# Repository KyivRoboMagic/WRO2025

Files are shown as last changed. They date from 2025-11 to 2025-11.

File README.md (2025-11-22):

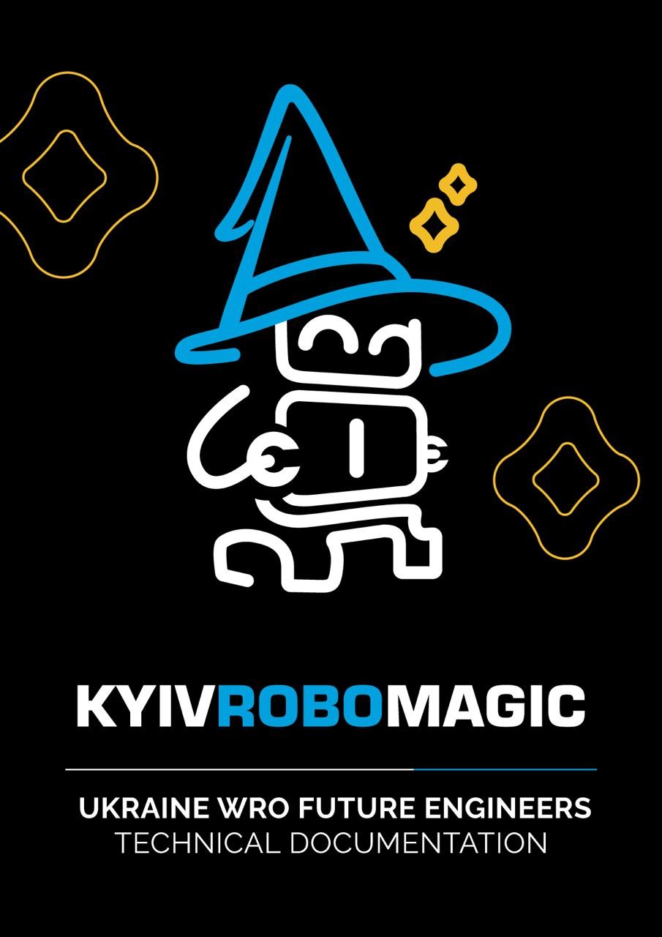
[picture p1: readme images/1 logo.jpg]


## Object Challenge: https://youtu.be/LZ57Y01bQvU

## Open Challenge: https://youtu.be/bDnhjbADkbo

# TABLE OF CONTENTS

INTRODUCTION — THE CAR THAT THINKS IN ANGLES (page 4)

## PART 1 — TEAM INTRO (page 6-9)
- 1.1. Who We Are
- 1.2. Our Ideology
- 1.3. Team Members
- 1.4. Preparation to WRO 2025
- 1.5. Calendar

## PART 2 — ENGINEERING SOLUTION (page 10-15)
- 2.1. General Ideology – The Car That Thinks in Angles
- 2.2. Robot Photo and General Dimensions
- 2.3. System Integration Specification
  - 2.3.1. System Architecture Overview
  - 2.3.2. Integration Logic
  - 2.3.3. Mechanical Subsystem
  - 2.3.4. Electrical Subsystem
  - 2.3.5. Control Software
- 2.4. Innovative Abilities

## PART 3 — ROBOT CONSTRUCTION (page 18-53)
- 3.1. Building Robot — Necessary Materials and Instruments
- 3.2. Electrical Components — Core Power and Control Elements
- 3.3. Mechanical Elements
- 3.4. Core Structure Elements
  - 3.4.0. Introduction
  - 3.4.1. Frame System — Base and Structural Parts
  - 3.4.2. Axle and Bearing Assembly
  - 3.4.3. Differential Mechanism
  - 3.4.4. Steering and Hinge System
  - 3.4.5. Turn and Steering Transmission
  - 3.4.6. Wheel and Tire Assembly
  - 3.4.7. Auxiliary and Module Elements

## PART 4 — PERFORMANCE (page 53)
- 4.1. Open Challenge Round
  - 4.1.1. Program Logic Overview
  - 4.1.2. Program Flow Summary
  - 4.1.3. Software Module Reference Table
  - 4.1.4. Detailed Program Functions’ Description
- 4.1.5. Open Challenge Strategy and Tactics
  - 4.1.5.1. System Strategy — Autonomous Field Navigation
  - 4.1.5.2. Tactical Implementation — Coordinated Sensor Logic
- 4.2. Obstacle Challenge Round
  - 4.2.1. Strategy
  - 4.2.2. Program Flow Summary
  - 4.2.3. Software Module Reference Table
  - 4.2.4. Detailed Program Functions’ Description

## PART 5 — RESOURCES LIBRARY

# INTRODUCTION — THE CAR THAT THINKS IN ANGLES

This document presents the engineering concept and integration framework of the WRO Future Engineers 2025 project — **“The Car That Thinks in Angles.”**

Created by **Kyivrobomagic**, it reflects our practical engineering culture:  
precise where it must be, experimental where it can be.

The idea was simple — to design a robot that doesn’t just move,  
but **understands its movement**.

Each subsystem — from the semi-spherical drivetrain to the sensor fusion core —  
was built to *think in geometry*, not in lines.

Mechanical, electrical, and software layers are integrated into a single responsive platform,  
capable of autonomous navigation and spatial reasoning.

---

## **Key Design Priorities**

- **Adaptive geometry:** torque transfer through a semi-spherical gear system allowing full-angle articulation.  
- **Sensor fusion:** LiDAR, IMU, and camera coordination for stable perception under any conditions.  
- **Power efficiency:** UPS-based 18650 system with DC-DC boost for 12 V drive and 5 V control logic.  
- **Real-time control:** multi-threaded C++ architecture ensuring predictive, low-latency motion.  

---

Every Kyivrobomagic robot carries a small dose of what we call **“engineering magic”** —  
not mystery, but **elegant simplicity** that makes a complex system work naturally.

This year, that magic is **geometry itself**.

# PART 1: TEAM INTRO

## **Who We Are**

We are **Kyivrobomagic** — a robotics team born in **2018 in Kyiv, Ukraine**.

Our team has changed over time, but the heart of it has always been the same:  
**Petro Moroz** and **Mark Biryukov**.

Together, we’ve grown into one of the **most awarded robotics teams from Ukraine**.

<p align="center">
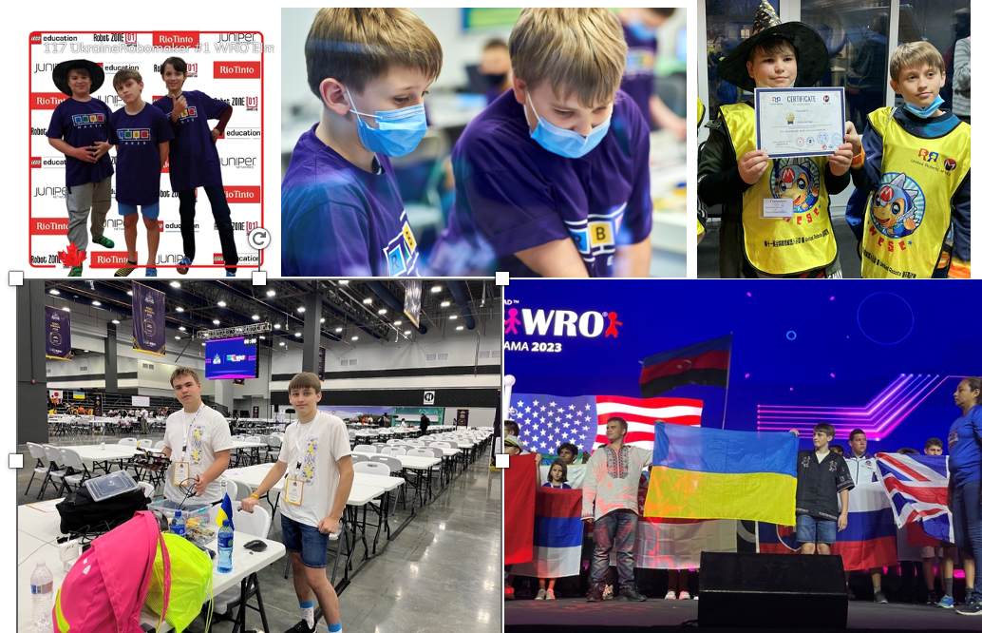
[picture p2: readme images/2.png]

</p>

## **Our Journey**

Our journey has been incredible.  
In **2020**, we earned **1st place** at **WRO Elementary**,  
in **2021** we took **silver**,  
then added another **silver at WRO Junior in Panama (2023)**,  
and reached the **Top 10 in Turkey (2024)** in the **Future Engineers** category.

But our story isn’t only about WRO.  
Each contest has taught us something new and made us stronger as a team.  
They brought fresh ideas, pushed us to think like real engineers, and inspired us to go further.

With every challenge, we learned not just how to build better robots,  
but also how to work together, solve problems creatively, and never give up.

For us, robotics is more than medals —  
it’s about **curiosity, friendship, and proving that Ukrainian kids can compete and win** on the world stage.

---

## **Our Ideology**

From the very beginning, our team has always appeared at competitions **dressed as wizards**.  
We are inspired by the famous quote:

> *“Any sufficiently advanced technology is indistinguishable from magic.”*

For us, it’s far more than words.  
At every competition, in every solution, we strive to create something so refined and well‑crafted  
that it amazes everyone and truly **feels like magic**.

We spend long hours working on programming and engineering,  
pouring not only knowledge but also imagination and creativity into our projects.

This is our philosophy:  
to transform complex technologies into something that inspires, fascinates, and opens new possibilities.  
**Technology as magic — and it is this magic that drives us forward.**

---

## **Team Members**

### **Petro Moroz — Engineering & Software**

In the team, Petro is responsible for engineering solutions, their implementation, and programming.  
For him, a robot is like a best friend, and every competition is a personal challenge.

He always strives to come up with something new —  
yet as simple and elegant as possible — to solve the tasks in the most efficient way.

Petro is also a talented coder — he likes to joke that he knows more programming languages than human ones.  
He proved his skills by taking **2nd place in Ukraine in programming among 9th graders**.

<p align="center">
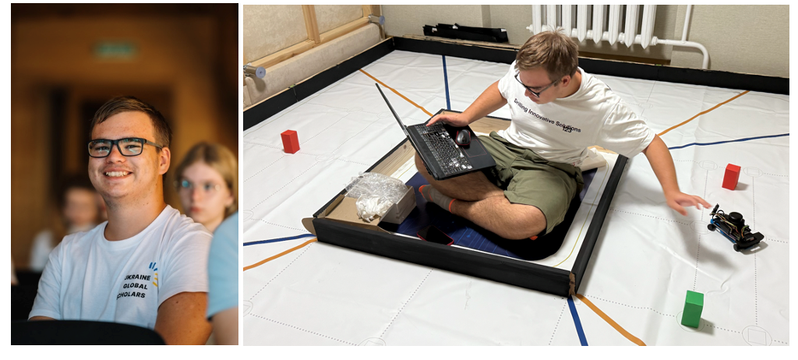
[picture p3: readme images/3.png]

</p>

## **Mark Biryukov — Software & Team Coordination**

Mark is responsible for software development and team coordination.  
He can find common ground with anyone and is a talented **mathematician and programmer**,  
a multiple prizewinner of math and programming Olympiads.

His greatest skill is his **incredible speed in finding solutions**.  
Mark quickly tests and implements ideas, helping the team move forward fast.

Thanks to his speed, energy, and openness, the team easily builds connections,  
communicates with ease, and always keeps a fun and positive spirit.

He is the team’s **“social glue.”**

<p align="center">
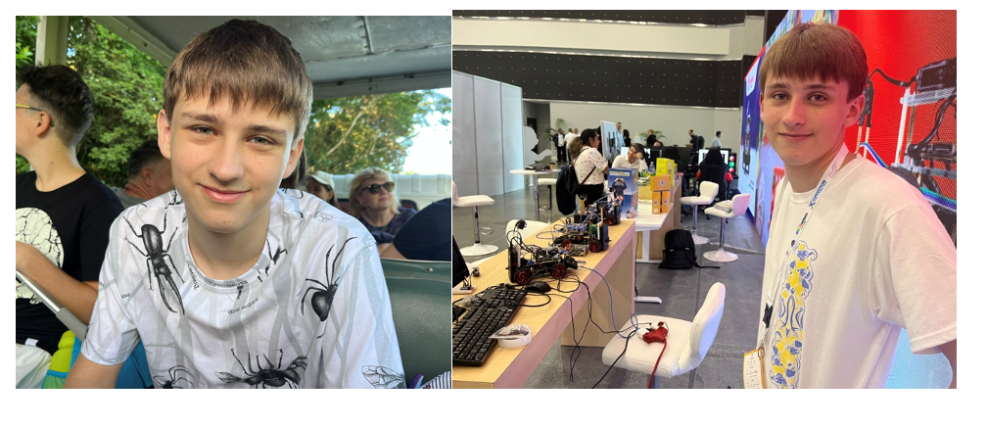
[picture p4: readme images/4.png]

</p>

## **Kyrylo Moroz — Design & Identity**

Our story wouldn’t be complete without mentioning our biggest fan and friend —  
**Petro’s younger brother, Kyrylo Moroz**.

He is only **12 years old**, but he is the one responsible for our **logo**,  
team **identity**, and making sure that everything about our team  
looks **stylish**, **consistent**, and **creative**.

Thanks to Kyrylo, our work is not only about engineering and programming,  
but also about **design, presentation, and imagination**.

<p align="center">
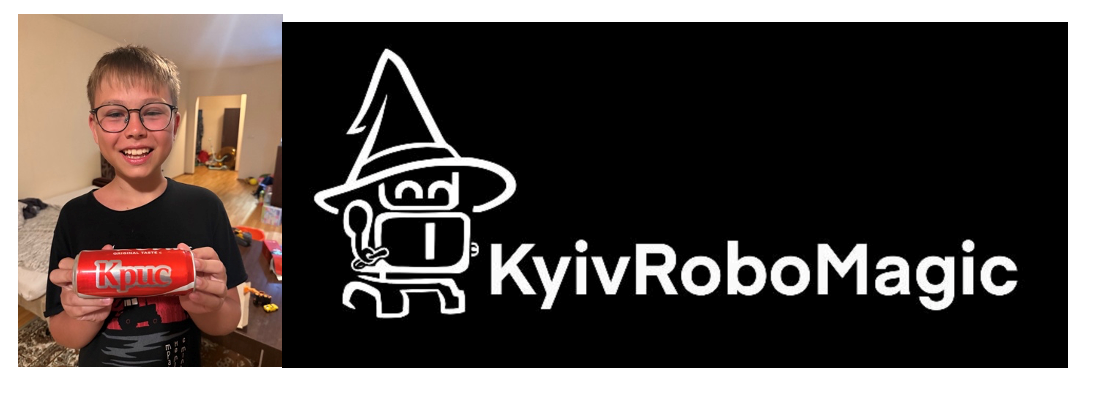
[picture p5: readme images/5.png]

</p>

## **Preparation to WRO 2025**

### **Logistic challenge as the main issue**

Because of the war in Ukraine, we had to move our work fully online.  
**Mark is in Kyiv**, while **Petro is in Cherkasy**, where his grandparents live.

Another important point is that we work **without a coach**,  
since in Ukraine there are no trainers in this category.  
This makes our journey not only about robotics, but also about  
**self-education, self-organization, and discipline** —  
without which none of this would be possible.

The preparation itself is also a challenge because of logistics.  
We break it into stages:

---

## **1. Research & Information Gathering**

We already had experience in the **Future Engineers** category last year,  
which gave us a strong foundation.

Still, we spent a lot of time studying the latest solutions for autonomous systems.  
For example, our chassis design is based on a **patented engineering idea**  
that had never been manufactured before.

Turning it from an abstract idea into a working prototype  
made us the first to implement it — and that’s where the **“magic”** begins.

---

## **2. Invention & Prototyping**

Most of the robot development takes place in Petro’s **“home lab” in Cherkasy** —  
actually, his and his brother’s bedroom 🙂 — equipped with a **3D printer**  
and access to parts.

We are always connected online, exchanging ideas  
and guiding the next steps of technical development.

---

## **3. Programming & Testing**

At this stage, we begin traveling to meet each other on weekends.  
This means spending **about three hours on the road** back and forth  
just to work together in person, test programs, and fine‑tune the design.

---

## **4. Finalization (Mini‑Camp)**

We plan the final stage as a **one‑week mini‑camp**  
during the autumn school break in October.

This is when we meet, live, and work together,  
finalizing the solutions we’ve been building for months.

---

# **Calendar**

Structurally, our preparation calendar looked like this.  
Since we are now in our final school years,  
it was especially important to stay on schedule  
and avoid major overlaps with exams and studies — and we managed to do so successfully.

We divided our work into clear stages, planned around school and competitions,  
which allowed us to maintain discipline, balance learning and robotics,  
and stay fully prepared for every challenge.

<p align="center">
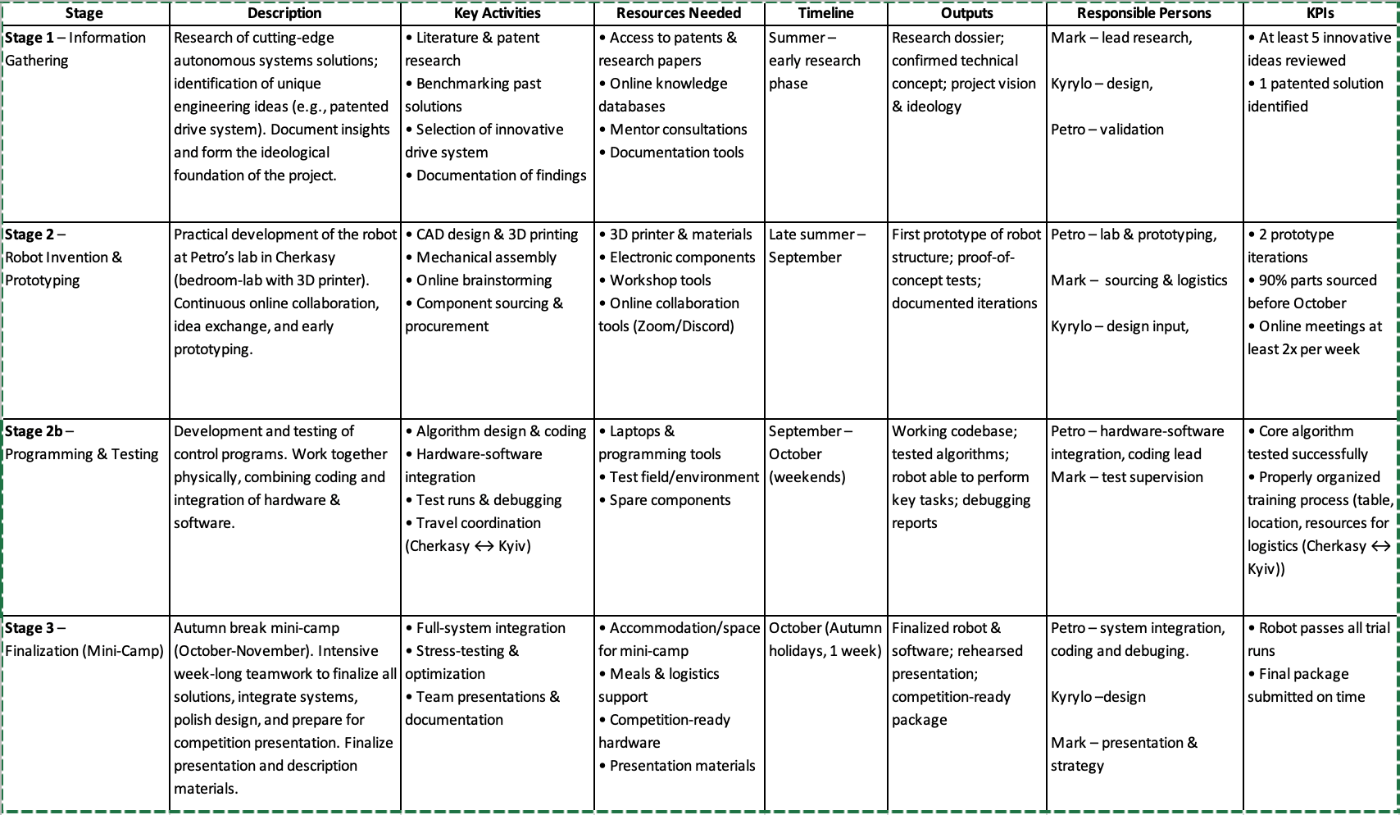
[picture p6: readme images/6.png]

</p>

# PART 2: ENGINEERING SOLUTION

## **General Ideology – The Car That Thinks in Angles**

### **1. From the Problem of Corners to the Geometry of Control**

Traditional vehicles are built for one-dimensional motion —  
they move forward and backward efficiently but lose precision when direction changes.

Most drivetrains are optimized for straight-line torque transfer,  
where every degree of deviation adds mechanical loss or instability.

This project started from a simple question:  
**can geometry itself improve control?**

Instead of treating steering angles as an obstacle,  
the robot uses them as part of its design logic.

The structure was built around the idea that **stability and control are not opposites** —  
they can be optimized together through geometry.

By rethinking how torque and direction interact,  
the robot achieves **smoother steering** and **higher mechanical accuracy**  
within a compact frame.

---

### **2. The Idea – The Car That Thinks in Angles**

The robot uses **one drive motor** and **one servo** to control all four wheels.  
Each wheel can rotate **up to 180°**, allowing:

- tight turning,  
- stable high-speed movement,  
- and minimal components without sacrificing precision.

The system relies on **mechanical synchronization**, not sensors on each wheel.  
The servo defines steering geometry,  
and the DC motor delivers torque.

Because all wheels are mechanically linked,  
motion remains consistent even at high rotation angles.

This design embodies **simplicity + reliability**:

- fewer moving parts,  
- fewer points of failure,  
- faster assembly,  
- easier debugging during competitions.

---

### **3. From Dimensions to Solutions**

Conventional robots operate in **two dimensions**: forward/backward and left/right.  
This system introduces a **third dimension — adaptive geometry**.

The robot dynamically adjusts orientation and turning angle  
based on real-time motion across the field.

To achieve this, it uses **three complementary sensors**:

- **LiDAR** — distance mapping + obstacle detection  
- **IMU** — stabilizes orientation between LiDAR updates  
- **Camera** — color, boundary, and line recognition  

Each sensor covers the weaknesses of the others.  
Together, they form a **robust and reliable perception system**  
even under variable lighting and surface conditions.

This setup is rare for WRO-level robots  
but proved **highly effective** in testing.

---

### **4. Key Technical Highlights**

#### **a) Unique Motion System**  
Each wheel rotates up to **180°**, yet the robot uses only **one motor + one servo**.  
This is extremely rare in competition robotics.

#### **b) Consistent Torque Delivery**  
The drivetrain maintains torque during steering through balanced geometry + load distribution.

#### **c) 3D-Printed Precision Components**  
Core parts — including advanced gear interfaces — were 3D-printed and tested.  
They demonstrate that **180° and even 360° torque transfer** is possible at this scale.

#### **d) Triple-Sensor Fusion**  
LiDAR + IMU + Camera → combined for superior navigation and robustness.

#### **e) Mechanical Reliability and Future Use**  
All components were validated under real competition conditions.  
They now form a **mechanical base** for future robot designs.

---

### **5. Summary**

**“The Car That Thinks in Angles”** is a compact and efficient robotic system  
that uses minimal components to achieve full control of movement.

The result is a **stable**, **fast**, and **reliable** platform  
that pushes the limits of what a single-motor robotic vehicle can do.

Every subsystem — drive, steering, sensing, structural design —  
was shaped through testing and iteration.

Its architecture blends:

- mechanical precision  
- geometric efficiency  
- sensor integration  

into one practical and elegant engineering solution.

---

# **Robot Photo and General Dimensions**

<p align="center">
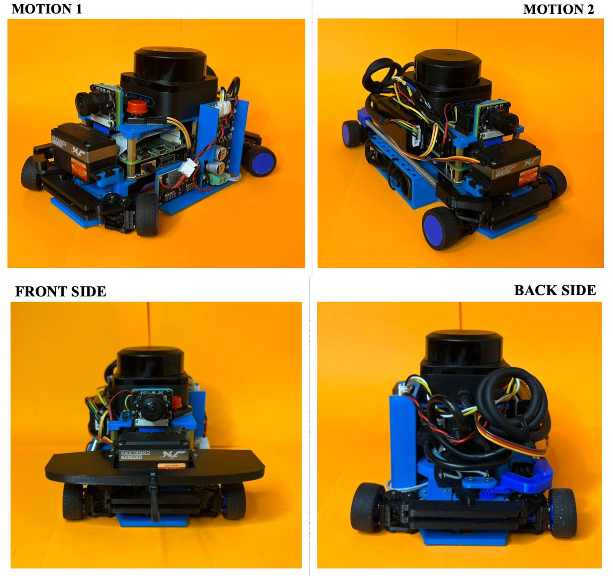
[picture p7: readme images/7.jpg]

</p>

<p align="center">
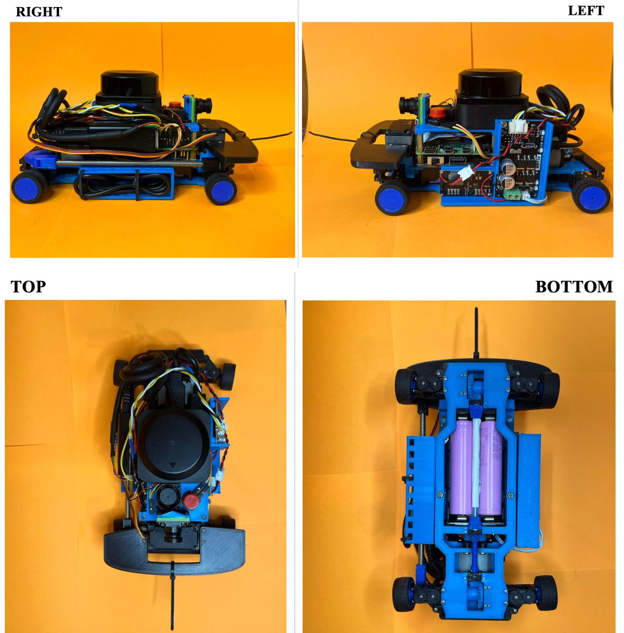
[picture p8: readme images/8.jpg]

</p>

## **Robot Dimensions**
- **Length:** 24 cm  
- **Width:** 12 cm  
- **Height:** 10 cm  

---

# **SYSTEM INTEGRATION SPECIFICATION**

## **1. System Architecture Overview**

The robot integrates four independent drive wheel modules, each connected through a **semi-spherical bevel gear system** inspired by patent **US5129275A**.

All four wheels are driven by a **single JGB37-520 12 V DC motor** through two differential units — one on each side — linked by the **main transmission shaft**.

Steering of all wheel modules is performed simultaneously by a **single global servo (JX PDI-4409MG)** providing up to **180° articulation** per wheel.

Each differential transfers torque to two wheel modules installed on custom 3D‑printed housings, enabling free rotation under multiple steering angles with balanced torque.

A **Raspberry Pi** coordinates all subsystems, processes sensor data, and controls motor + servo through PWM and digital channels.

### **Core components**
- **Motor:** JGB37-520 DC Motor (12 V)  
- **Motor Driver:** Cytron MD13S (PWM ≤ 20 kHz)  
- **Servo:** JX PDI-4409MG (180° steering)  
- **Main Controller:** Raspberry Pi 4 Model B (8 GB)  
- **Power Source:** UPS HAT with 2 × 18650 Li-ion (7.4 V nominal)  
- **Voltage Regulation:** TPS61088 (5V → 12V boost)  
- **Sensors:** RPLIDAR S3, BNO085 IMU, Waveshare OV5647 Camera  
- **Chassis:** Fully custom 3D‑printed modular frame  

---

## **2. Integration Logic**

The **Raspberry Pi 4B** generates PWM for the Cytron MD13S and the steering servo.  
The motor driver regulates torque and speed; the servo defines steering geometry.

### **Power Distribution**
- UPS HAT powers control electronics (**5 V / 3.3 V**)  
- TPS61088 boosts **5 V → 12 V** for the DC motor  
- 2S Li-ion battery pack is the unified input  

### **Sensor Interfaces**
- **LiDAR:** USB (mapping + obstacle detection)  
- **IMU (BNO085):** I²C (orientation, stabilization)  
- **Camera:** CSI ribbon cable (vision processing)  

The Pi fuses all sensor data, computes navigation in C++, and sends real‑time motion commands.

---

## **3. Mechanical Subsystem**

A fully custom 3D‑printed semi-spherical bevel gear system distributes torque from the motor into two side differentials.

Each differential powers two wheel modules via compact coupling shafts.

This structure:
- preserves wheel orientation at any steering angle  
- minimizes friction  
- simplifies replacement of subassemblies  
- maintains alignment across the chassis  

---

## **4. Electrical Subsystem**

| Component | Function | Specification |
|---|---|---|
| **Power Source** | Primary supply | 2 × 18650 Li-ion (7.4 V, 2S) |
| **Voltage Regulation** | Boost 5V → 12V | TPS61088, 30 W |
| **Power Distribution** | Logic rails | UPS HAT B |
| **Motor Driver** | Drive control | Cytron MD13S (13 A, 6–30 V) |
| **Motor** | Main torque | JGB37-520 DC Motor (12 V) |
| **Servo** | Steering | JX PDI-4409MG |
| **Sensors** | Perception | LiDAR S3, BNO085, OV5647 Camera |
| **Controller** | Navigation | Raspberry Pi 4B (8 GB) |

---

## **5. Control Software**

- **C++** → motor control, navigation logic  
- **Python** → IMU interface  
- **PWM** → drive + steering actuation  
- **Sensor fusion** → LiDAR + IMU + Camera  
- **Feedback loops** → heading + stability correction  

---

## **Summary**

The system integrates:
- single‑motor + global‑servo drivetrain  
- adaptive sensing  
- efficient power management  

Resulting in a compact, stable, full‑angle steering platform with reliable sensing and control.

---

## **Innovative Abilities**

| Ability | Description |
|---|---|
| **Full‑Torque Steering** | Maintains torque during 180° wheel rotation |
| **Adaptive Response** | LiDAR + IMU + Camera fusion for stable navigation |
| **Efficient Power Control** | UPS HAT + TPS61088 ensure stable motor + logic power |

# PART 3: ROBOT CONSTRUCTION

## **Building Robot – Necessary Materials and Instruments**

## **1. 3D Printer: Ender V3 — Detailed Usage & Specifications**

<p align="left">
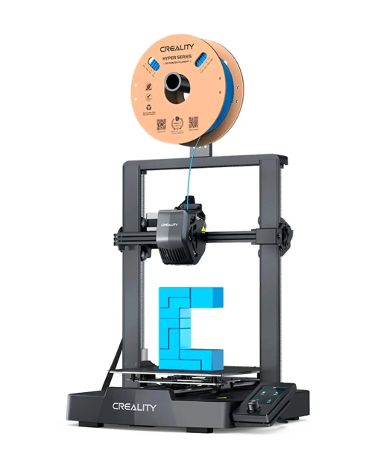
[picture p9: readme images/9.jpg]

</p>

This is the printer personally owned and used in my workshop for all prototype and final component manufacturing.  
It was used to fabricate the majority of the robot’s mechanical and structural parts.

Its **automatic bed leveling system** saves significant setup time —  
a major advantage, as manual leveling is often one of the most time‑consuming and error‑prone steps in 3D printing.

Using a **0.2 mm nozzle** enabled the production of small, detailed parts with:
- superior dimensional accuracy  
- smooth surface finish  
- tight bearing alignment  
- reliable tolerance for rotating assemblies  

These characteristics were crucial for the semi‑spherical gear interfaces, differential units, and steering components.

---

## **Ender V3 Technical Specifications**

| **Parameter** | **Specification** |
|---|---|
| **Type** | FDM (Fused Deposition Modeling) |
| **Build Volume** | 220 × 220 × 250 mm |
| **Recommended Filament Types** | PLA, PETG, TPU |
| **Filament Diameter** | 1.75 mm |
| **Nozzle Diameter** | 0.2 mm (standard, interchangeable) |
| **Nozzle Temperature Range** | up to 260 °C |
| **Bed Temperature Range** | up to 100 °C |
| **Layer Resolution** | 0.1 – 0.35 mm |
| **Print Speed** | up to 180 mm/s (recommended ≤ 120 mm/s for precision) |
| **Automatic Leveling** | CR Touch Sensor + strain gauge Z‑offset calibration |
| **Connectivity** | SD card, USB‑C |
| **Control Interface** | 4.3″ color display with Creality OS |
| **Frame** | All‑metal structure with dual Z‑axis & belt tensioners |
| **Supported File Formats** | STL, OBJ, AMF, G-code |
| **Slicing Software** | Creality Print, Cura, PrusaSlicer |
| **Power Supply** | 100–240 V AC (50/60 Hz) |
| **Noise Level** | < 45 dB (silent stepper drivers) |
| **Printer Dimensions** | 490 × 490 × 510 mm |
| **Weight** | ≈ 7.1 kg |

---

## **2. Printing Plastic**

<p align="center">
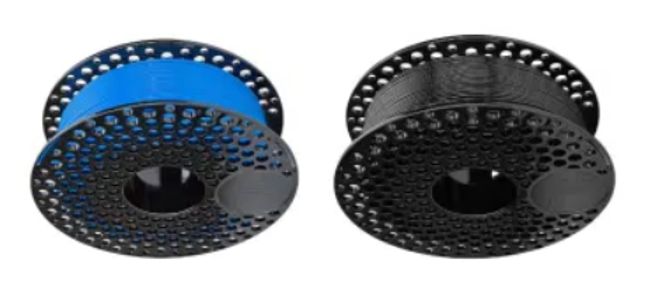
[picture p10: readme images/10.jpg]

</p>

The color itself is not critical, but it can slightly affect surface texture, print strength,  
and layer bonding. In my experience, **black PETG from CR** produced the most stable  
and consistent results on the Ender‑3 V3 printer.

The printer operates optimally at **230 °C nozzle temperature**,  
but users should run small calibration prints to tune performance  
for their specific filament brand and ambient environment.

Mechanical and aesthetic properties vary among manufacturers,  
so it's recommended to check **public filament tests** and **community benchmarks**  
before printing structural components such as gears, holders, and load‑bearing frames.

---

## **PETG Technical Specifications**

| **Parameter** | **Specification** |
|---|---|
| **Filament Type** | PETG (Polyethylene Terephthalate Glycol) |
| **Color** | Black / Blue |
| **Filament Diameter** | 1.75 mm |
| **Printing Temperature Range** | 230 – 250 °C |

---

# ELECTRICAL COMPONENTS — CORE POWER AND CONTROL ELEMENTS

## **1. Raspberry Pi 4 Model B – Central Control Unit**

<p align="left">
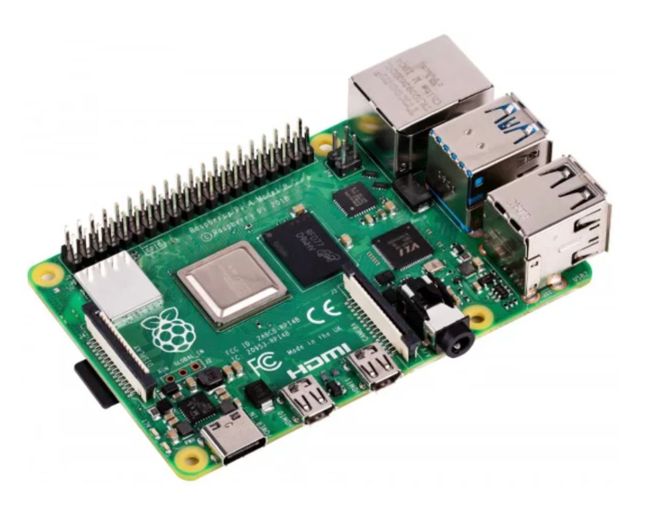
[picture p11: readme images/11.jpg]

</p>

This board serves as the **central control and coordination unit** of the robot.  
It manages all communication channels, motor coordination, and sensor data processing.

Thanks to its processing capacity, it can **simultaneously handle**:

- LiDAR data  
- IMU readings  
- Camera input  
- Motor control tasks  

The main navigation + control logic is written in **C++**, ensuring high-speed, low-latency execution.  
A lightweight **Python** script interfaces the **BNO085 IMU** library, simplifying data access and fusion.

An **UPS HAT (B)** module provides uninterrupted power, reducing development time, increasing reliability,  
and protecting the Raspberry Pi from power drops during motor load spikes.

The Raspberry Pi 4B was chosen for its:

- strong community support  
- abundant documentation  
- compatible peripherals  
- excellent performance for real-time robotics  

---

## **Raspberry Pi 4 Model B — Technical Specifications**

| **Parameter** | **Specification** |
|---|---|
| **Model** | Raspberry Pi 4 Model B |
| **RAM** | 8 GB LPDDR4 3200 |
| **Processor** | Broadcom BCM2711 — Quad-core Cortex A72 (ARM v8, 1.5 GHz) |
| **GPU** | VideoCore VI (OpenGL ES 3.x, Vulkan) |
| **Network / Connectivity** | Gigabit Ethernet, WiFi 2.4/5.0 GHz, Bluetooth 5.0, BLE |
| **USB Ports** | 2 × USB 3.0, 2 × USB 2.0 |
| **Display Outputs** | 2 × micro HDMI (dual displays up to 4K) |
| **Video / Audio** | H.265 4Kp60, H.264 1080p60, 4Kp30 encode/decode |
| **Storage Interface** | microSD slot |
| **Power Supply** | USB‑C 5.1 V / 3 A |
| **GPIO Header** | 40‑pin GPIO (Pi‑compatible) |
| **Dimensions** | 88 × 58 × 19.5 mm |
| **Operating Temperature** | 0°C to +50°C |
| **Operating System** | Raspberry Pi OS, Ubuntu, ARM Linux |
| **Typical Applications** | Robotics, IoT, education, desktop |
| **Manufacturer** | Raspberry Pi Ltd (UK) |
| **Official URL** | https://www.raspberrypi.com/products/raspberry-pi-4-model-b/ |

---

## **2. Sunon KD0501PFB3-8 Micro Fan – Essential Cooling Element**

Although small, this fan plays a **critical role in maintaining thermal stability** of the system.  
Without active cooling, the **Raspberry Pi 4 overheats within minutes**, reaching temperatures where the CPU throttles  
and can no longer operate reliably.

This miniature fan dramatically improves cooling performance — lowering the CPU temperature so the board stays:

- stable  
- responsive  
- touch-safe  
- fully operational under maximum load  

To reduce **noise and vibration**, a thin layer of **double‑sided adhesive tape** was placed between the fan and the 3D‑printed frame.  
This acts like soft **acoustic foam**, absorbing micro‑vibrations and preventing resonance with the chassis.

As a result, the fan becomes **almost silent** while maintaining full airflow efficiency.

---

## **Sunon KD0501PFB3-8 — Technical Specifications**

<p align="left">
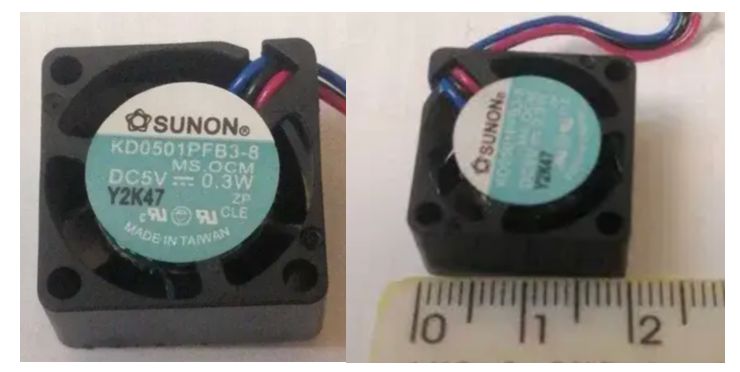
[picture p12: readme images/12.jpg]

</p>

| **Parameter** | **Specification** |
|---|---|
| **Type** | DC Brushless Cooling Fan |
| **Manufacturer** | Sunon |
| **Model** | KD0501PFB3-8 |
| **Dimensions** | 20 × 20 × 10 mm |
| **Rated Voltage** | 5 V DC |
| **Operating Voltage Range** | 3.5 – 5.5 V |
| **Rated Current** | 0.06 A |
| **Rated Power Consumption** | 0.3 W |
| **Rated Speed** | 10,000 ±15% RPM |
| **Air Flow** | 1.0 CFM |
| **Static Pressure** | 3.6 mm H₂O |
| **Noise Level** | 22 dBA |
| **Bearing Type** | Vapo Bearing (MagLev technology) |
| **Connector Type** | 2-wire (Red +, Black –) |
| **Frame Material** | Thermoplastic (UL 94V-0) |
| **Weight** | ~4 g |
| **Operating Temperature Range** | –10 °C to +70 °C |
| **Expected Life** | 50,000 hours @ 40 °C |

---

## **3. RPLIDAR S3 – High-Precision 2D LiDAR Scanner**

<p align="left">
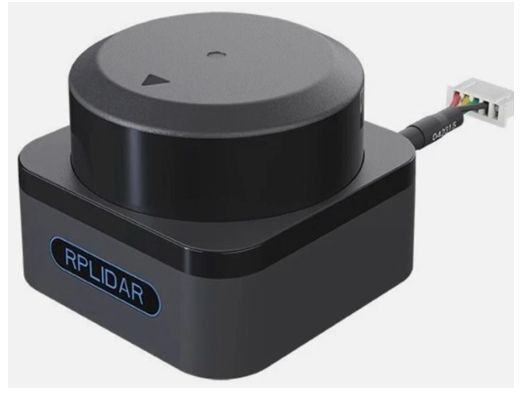
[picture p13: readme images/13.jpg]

</p>

This LiDAR sensor became a **turning point** in the robot’s spatial awareness system.

In the previous generation, the robot relied solely on the **camera for navigation**, meaning it had **no memory of its environment** — every run started “from zero.”  

With the introduction of the **RPLIDAR S3**, the robot can now:

- build a persistent **2D map** of its surroundings  
- perform **precise localization**  
- correct its path in real time  
- operate reliably regardless of lighting or color conditions  

Unlike the camera, the LiDAR is **immune to lighting changes**, shadows, reflections, and color inconsistencies.  
Earlier robots often confused:

- **red cubes** with **orange lines**,  
- **gray walls** with the **floor**,  
- or misread the field under shifting lighting conditions.

The RPLIDAR S3 eliminates these problems completely.

By combining **LiDAR mapping** with **IMU-based orientation correction**, the robot achieves:

- unprecedented stability  
- high navigation accuracy  
- reliable field awareness  

allowing the camera to focus **only on object detection**, not full scene interpretation.

---

## **RPLIDAR S3 — Technical Specifications**

| **Parameter** | **Specification** |
|---|---|
| **Model** | RPLIDAR S3 |
| **Type** | 2D 360° laser scanner (DTOF / SL TOF) |
| **Distance Range (70% refl.)** | 0.05–40 m |
| **Distance Range (10% refl.)** | 0.05–15 m |
| **Distance Range (2% refl.)** | 0.05–5 m |
| **Blind Range** | 0.05 m |
| **Sampling Rate** | Up to 32 kHz |
| **Scan Frequency** | 10–20 Hz |
| **Angular Resolution** | 0.1125°–0.225° |
| **Ranging Resolution** | 10 mm |
| **Range Accuracy** | ±30 mm |
| **Ambient Light Immunity** | ≥80,000 Lux (sunlight resistant) |
| **Communication Interface** | TTL UART (1 Mbit/s) |
| **Laser Safety** | Class 1 (eye safe) |
| **Power Supply** | 5 V DC, ~500 mA |
| **Dimensions** | 59.8 × 55.6 × 41.3 mm |
| **Weight** | ~115 g |
| **Operating Temperature** | –10 °C to +60 °C |
| **Applications** | Robotics, AGV/AMR, SLAM, UAV avoidance |
| **Manufacturer** | SLAMTEC (China) |
| **Official URL** | https://www.slamtec.com/en/S3 |

---

## **4. Waveshare OV5647 5 MP Wide-Angle Camera Module — Technical Description**

<p align="left">
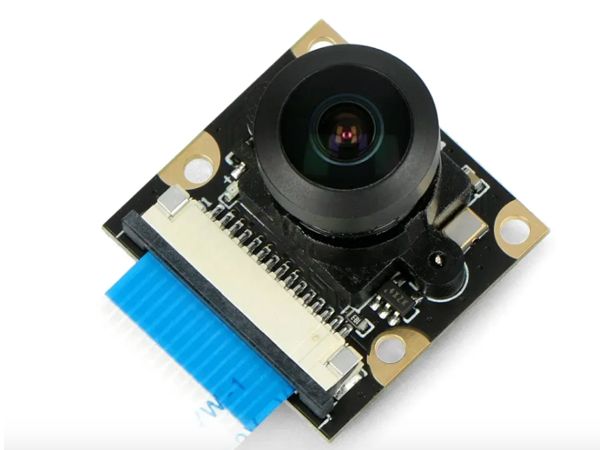
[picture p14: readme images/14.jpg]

</p>

This camera module is the same model used in last year’s robot design.  
It is built on the **OV5647 5‑megapixel sensor** and operates natively with all **Raspberry Pi boards** via the CSI interface.

Despite being lightweight and simple, it is **highly optimized for Raspberry Pi**, providing stable and predictable behavior in robotics applications.

The camera captures **RGB images at up to 30 FPS (640×480)**.  
Although modest compared to modern high‑speed camera systems, this performance is **fully sufficient for fast robot movement** when paired with efficient image-processing algorithms.

### **Wide-Angle Advantage (160° FoV)**

A major benefit of this module is its **160‑degree wide-angle lens**, dramatically expanding the field of view.  
This allows the robot to:

- detect walls more reliably  
- track boundaries continuously  
- reduce blind spots  
- maintain stable navigation even in narrow or irregular field layouts  

### **Role in the New Architecture**

Unlike last year’s robot, **the camera no longer determines field position**.  
Localization is now handled entirely by the **LiDAR + IMU system**, resulting in:

- far higher positional stability  
- no more double-scanning of lines  
- reduced navigation errors  
- cleaner division of sensing roles  

The camera now focuses solely on:

- wall detection  
- color marker identification  
- boundary tracking  
- visual assistance in obstacle detection  

This separation significantly improves system accuracy and reduces computational load.

---

## **Waveshare OV5647 — Technical Specifications**

| **Parameter** | **Description / Value** |
|---|---|
| **Sensor Model** | OV5647 |
| **Image Sensor Type** | CCD, 1/4" |
| **Resolution** | 5 MP (2592×1944) |
| **Image Format** | RGB |
| **Supported Video Resolution** | Up to 1080p |
| **Max Frame Rate** | 30 FPS |
| **Recommended Mode** | 640×480 @ 30 FPS |
| **Field of View** | 160° wide-angle lens |
| **Standard FoV (base module)** | ~73° |
| **Connection Interface** | CSI |
| **Raspberry Pi Compatibility** | Pi 4B, 3B+, 3B, 2B, 1B, Zero series |
| **Zero Adapter Options** | 150 mm / 300 mm adapters |
| **Lens Characteristics** | Factory-mounted, Pi‑tuned optics |
| **CPU Load** | Minimal (hardware-accelerated pipeline) |
| **Primary Purpose** | Wide-angle real-time vision |
| **Form Factor** | Direct CSI‑port camera module |

---

## **5. BNO085 9‑DOF IMU Fusion Breakout (Adafruit 4754) – Inertial Compensation System**

<p align="left">
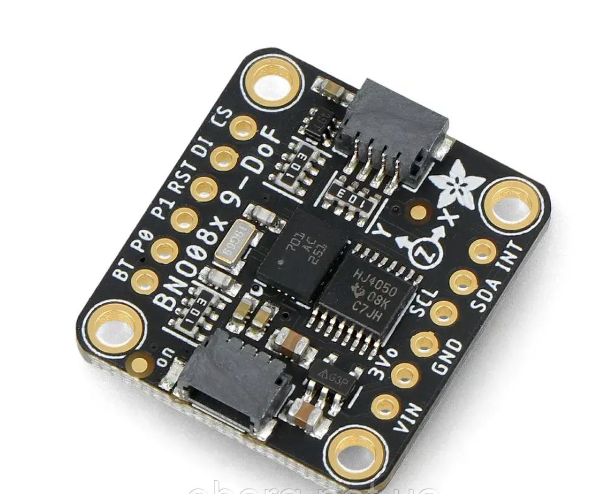
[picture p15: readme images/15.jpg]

</p>

While the RPLIDAR S3 provides spatial mapping, it operates at roughly **one measurement every 100 ms**—an eternity in control‑loop terms (about one data point per ~10 cm of travel).  

The **BNO085 IMU** fills this temporal gap by delivering **continuous inertial data**, maintaining motion awareness between LiDAR samples.

Although IMUs experience long‑term drift, their **short‑term accuracy** makes them ideal for interpolating robot motion between LiDAR frames, ensuring:

- smooth trajectory estimation  
- stable orientation  
- consistent turning logic  

### **Integration Challenge**

Integrating this IMU was one of the most challenging stages of the build:

- **SPI communication failed** due to unstable responses and noise.  
- Consultation with **Bryan Siepert** (BNO085 library author) confirmed SPI is unreliable in this configuration.  
- **I²C also failed initially**, not initializing consistently.  

The breakthrough came from using the **official Python driver**, which proved fully stable.  
A small Python service now runs in parallel with the C++ navigation engine:

- Python module → handles IMU fusion & quaternions  
- C++ program → receives results via internal data pipe  

This hybrid architecture merges the **reliability of Python** with the **performance of C++**.

---

## **BNO085 — Technical Specifications**

| **Parameter** | **Specification** |
|---|---|
| **Model** | BNO085 9-DOF IMU Fusion Breakout (Adafruit 4754) |
| **Function** | 3-axis accelerometer + 3-axis gyroscope + 3-axis magnetometer with fusion |
| **Processor** | ARM Cortex M0 running CEVA SH-2 firmware |
| **Sample Rate** | Up to 1 kHz |
| **Report Types** | Orientation, quaternion, lin. acceleration, gravity, raw/calibrated data, motion detection |
| **Interface** | I²C (default), optional UART/PSI |
| **Logic Voltage** | 3.3 V (5 V tolerant) |
| **Power Supply** | 3.3–5 V |
| **Dimensions** | 25.6 × 22.7 × 4.6 mm |
| **Weight** | ~2.5 g |
| **Mounting** | Breakout board + STEMMA QT/Qwiic |
| **Operating Temperature** | –40 °C to +85 °C |
| **Communication Speed** | I²C up to 400 kHz / UART 115,200 bps |
| **Applications** | Robotics, AR/VR, tracking, IMU fusion |
| **Manufacturer** | Adafruit / Hillcrest Labs |
| **Official URL** | https://www.adafruit.com/product/4754 |

---

## **6. Waveshare UPS HAT (B) – Uninterruptible Power Supply Module for Raspberry Pi**

<p align="left">
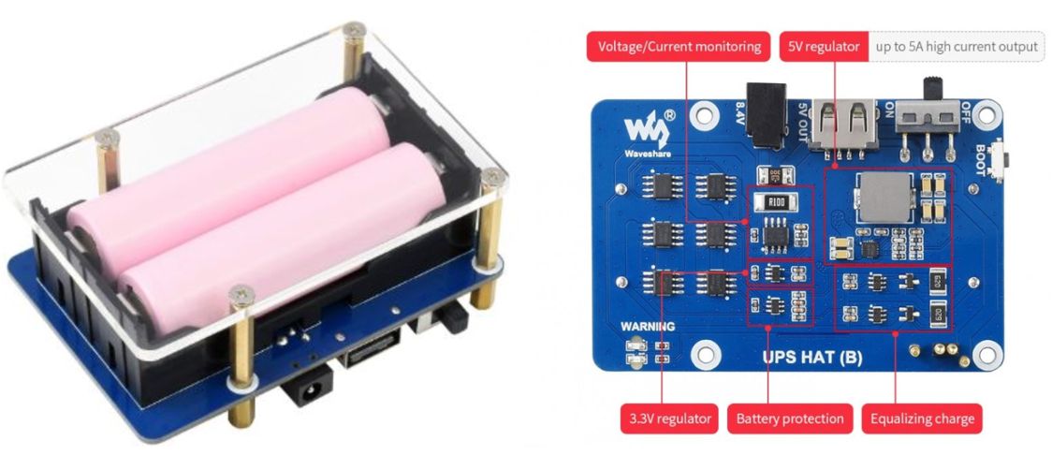
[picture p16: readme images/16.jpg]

</p>

The **Waveshare UPS HAT (B)** serves as the **primary power-stabilization unit** for the robot’s control system, ensuring continuous and stable operation of the Raspberry Pi 4 and all electronics even under dynamic motor loads.

In the previous year’s design, frequent **brown-out events** occurred — moments when sudden current spikes from motors or servos caused the Raspberry Pi to reboot.  
This UPS module **eliminates that problem entirely**:

- delivers **up to 5 A** continuous current  
- provides **stable 5 V and 3.3 V rails**  
- includes **real‑time battery monitoring** through I²C  
- **continues powering the Pi even while charging**  
- routes all power **through the UPS**, preventing undervoltage drops  

Although physically large and challenging to integrate mechanically, the reliability improvement is dramatic and essential for uninterrupted LiDAR, IMU, and camera processing.

---

## **Waveshare UPS HAT (B) — Technical Specifications**

| **Parameter** | **Specification** |
|---|---|
| **Model** | Waveshare UPS HAT (B) |
| **Output Voltage** | 5 V DC regulated |
| **Max Output Current** | Up to 5 A continuous |
| **Charger Input** | 8.4 V / 2 A |
| **Control Bus** | I²C — live monitoring (voltage, current, power, remaining capacity) |
| **Battery Support** | 2 × 18650 Li-ion cells |
| **Battery Protection** | Overcharge, overdischarge, overcurrent, short circuit, reverse polarity, balancing charge |
| **Automatic Switchover** | Yes — seamless transition to battery when power fails |
| **GPIO / Connector** | Pogo-pin connector (minimal GPIO usage) |
| **Compatibility** | Raspberry Pi 3 / 3B+ / 4B (+ likely Pi 5) |
| **Communication Interface** | I²C @ address 0x36 (BQ27441 or equivalent) |
| **Dimensions** | 56 × 85 mm |
| **Mounting Hole Size** | 3.0 mm |
| **Operating Temperature** | 0 °C – 50 °C |
| **Manufacturer** | Waveshare International |
| **Applications** | Robotics, Raspberry Pi UPS, industrial IoT |
| **Official URL** | https://www.waveshare.com/wiki/UPS_HAT_(B) |

---

## **7. DC‑DC Step‑Up (Boost) Module – TI TPS61088**

<p align="left">
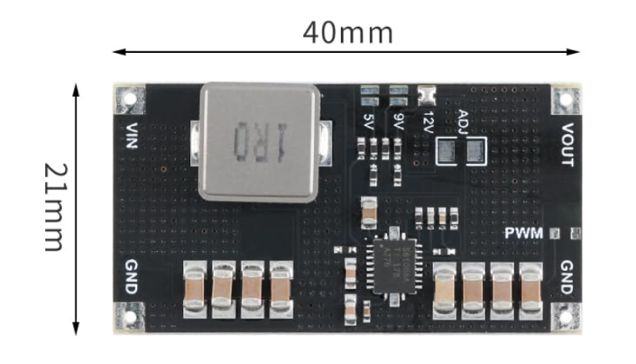
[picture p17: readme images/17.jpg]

</p>

This module plays a **critical role in power conversion**, boosting the 5 V rail from the UPS HAT (B) to the **12 V required** by the Cytron MD13S motor driver and the robot’s DC gear motors.

The **TPS61088** chip is well known for its **exceptional current capability** — up to **10 A peak**, far exceeding typical hobby-grade converters (2.5–5 A).  
This higher margin ensures:

- stable motor torque  
- no voltage sag during acceleration or turning  
- clean, synchronized drivetrain behavior  

Despite its compact size, the module offers:

- precise output tuning via onboard potentiometer  
- optional configuration headers  
- high efficiency and robust protection  

In this robot, the converter forms the **power bridge** between:

- **5 V logic system** (UPS HAT output)  
- **12 V actuator rail** (motor + driver supply)

It was carefully calibrated for **stable 12 V** operation even under rapid motor load variations.

---

## **TI TPS61088 Boost Converter — Technical Specifications**

| **Parameter** | **Specification** |
|---|---|
| **Module / IC** | DC-DC Step-Up (Boost) – TI TPS61088 |
| **Input Voltage** | 2.7–10 V DC |
| **Output Voltages** | 5 V / 9 V / 12 V selectable |
| **Max Output Power** | Up to 30 W |
| **Typical Output Capability** | 5 V → 5–6 A, 9 V → 3.3 A, 12 V → 2.5 A |
| **Efficiency** | Peak > 95% |
| **Switching Frequency** | ~200 kHz–2.2 MHz (typically ~1 MHz) |
| **Control Modes** | PFM/PWM auto or selectable |
| **Protection** | Overcurrent, cycle-by-cycle limiting, thermal shutdown |
| **Ripple / Noise** | Low with appropriate capacitors |
| **Inductor** | High‑current shielded (onboard) |
| **Operating Temperature** | –40 °C to +85 °C |
| **Dimensions** | Compact PCB module (varies by vendor) |
| **Reference Datasheet** | https://www.ti.com/lit/gpn/TPS61088 |

---

## **8. Cytron MD13S – 13A 6–30V DC Motor Driver**

<p align="left">
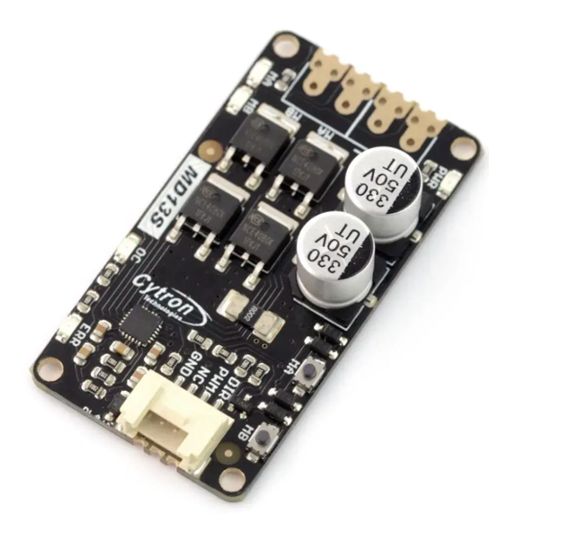
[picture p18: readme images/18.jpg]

</p>

The **Cytron MD13S** serves as the **main motor control unit** for each DC drive motor.  
It is a robust, competition‑grade driver designed for **high‑current, high‑stress** robotics applications.

Earlier prototypes used an L293D‑based driver, which failed during stress testing — specifically burning out during a collision when the motor produced a sudden reverse surge.  
The **MD13S handled the same tests without any damage**, thanks to:

- strong overcurrent protection  
- solid‑state H‑bridge design  
- high efficiency  
- 13 A continuous current capability  

Although physically larger than lighter alternatives, its **thermal stability**, **current margin**, and **plug‑and‑play simplicity** make it the ideal choice for the drivetrain.

Once installed, it requires almost no maintenance and performs flawlessly under continuous operation.

---

## **Cytron MD13S — Technical Specifications**

| **Parameter** | **Specification** |
|---|---|
| **Model** | Cytron MD13S 13A 6–30V DC Motor Driver |
| **Motor Channel** | 1 (Single brushed DC motor) |
| **Operating Voltage** | 6–30 V DC |
| **Continuous Current** | 13 A |
| **Peak Current** | 30 A (≤10 s) |
| **Logic Voltage** | 3.3 V / 5 V compatible |
| **PWM Frequency** | Up to 20 kHz |
| **Control Modes** | Sign‑Magnitude PWM / Locked‑Antiphase |
| **Direction Control** | DIR pin |
| **Connectors** | Terminal blocks (power & motor), GROVE logic connector |
| **Protection** | Over‑current limit, solid‑state H‑bridge, NMOS |
| **Efficiency** | ~95% |
| **Dimensions** | 61 × 33 mm |
| **Mounting Holes** | 4 × 3.2 mm |
| **Operating Temperature** | –10 °C to +60 °C |
| **Applications** | Robotics, automation, Arduino/RPi motor control |
| **Manufacturer** | Cytron Technologies |
| **Official URL** | https://www.cytron.io/p-13amp-6v-30v-dc-motor-driver |

---

## **9. JGB37-520 DC Gear Motor (12 V) – High-Power Drive Unit**

<p align="left">
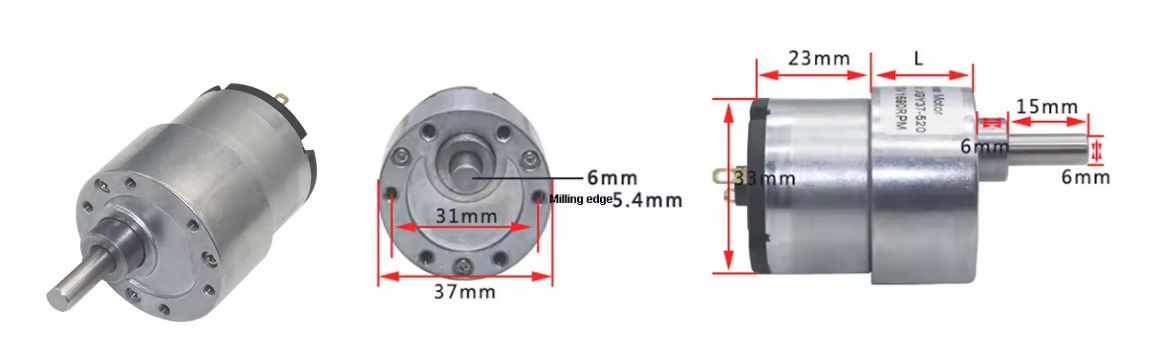
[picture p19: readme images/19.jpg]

</p>

This motor serves as the **main propulsion unit** for the robot’s four-wheel drive system, providing both forward and reverse motion.

Compared to last year’s robot, the current platform is **larger, heavier, and significantly more power-demanding**.  
Extensive tests demonstrated that small 6–9 V motors were insufficient for:

- fast acceleration  
- high-speed traversal  
- overcoming friction in the semi-spherical gear system  

The **JGB37-520 (12 V)** motor fully meets these requirements.

Although the model includes a **planetary gearbox**, the robot is configured to operate with **minimal effective gear reduction**, maximizing shaft RPM to achieve extremely high linear acceleration.  
This “brute-force speed” approach provides:

- rapid movement  
- strong and stable torque  
- excellent response to motor commands  

It is one of the most reliable and high‑performance brushed DC motors available for medium-size robotics.

---

## **JGB37-520 DC Gear Motor — Technical Specifications**

| **Parameter** | **Specification** |
|---|---|
| **Model** | JGB37-520 DC Gear Motor (12 V) |
| **Rated Voltage** | 12 V DC |
| **Gearbox Type** | Metal planetary gearbox |
| **Gear Ratios (available)** | 1:20, 1:30, 1:60, 1:90 |
| **No Load Speed (12 V)** | 500 rpm (R20) / 320 rpm (R30) / 170 rpm (R60) / 110 rpm (R90) |
| **Rated Speed & Torque (R20)** | ~390 rpm @ 1 kg·cm |
| **Stall Torque (R60)** | ~9.2 kg·cm |
| **No Load Current** | ~0.25 A |
| **Stall Current** | 3.2–3.9 A |
| **Motor Type** | Brushed DC |
| **Shaft Type** | 6 mm D‑shaped |
| **Encoder Option** | Available (Hall sensor) |
| **Dimensions** | Ø37 mm × 65–80 mm |
| **Weight** | 200–230 g |
| **Operating Voltage Range** | 6–15 V DC |
| **Efficiency** | 60–75% |
| **Operating Temperature** | –10 °C to +60 °C |

---

## **10. JX PDI-4409MG Coreless Metal Gear Digital Low Profile Servo – Steering System Actuator**

<p align="left">
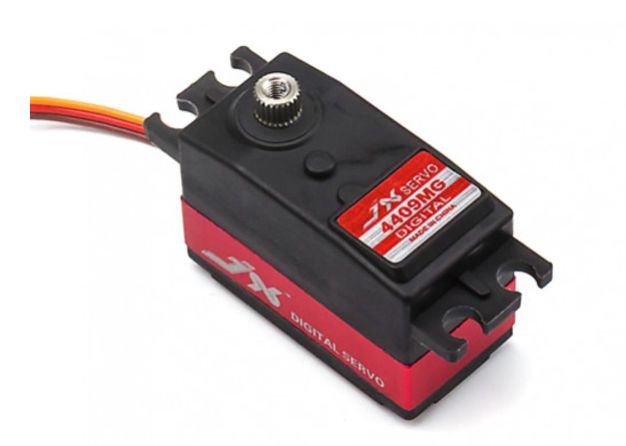
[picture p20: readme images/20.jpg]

</p>

This servo forms the **core of the steering system**, responsible for turning **all four wheels simultaneously** through the robot’s synchronized steering linkage.

While the JGB37-520 DC motors generate linear propulsion, the **JX PDI-4409MG** manages all directional control.  
Its **coreless motor** and **metal geartrain** provide:

- high torque  
- fast angle response  
- excellent precision  
- stability under vibration  

Multiple stress tests confirmed that this servo can sustain the mechanical load needed to steer all wheels equally, even during:

- high-speed turns  
- collisions  
- rapid angle changes  

The servo maintains position reliably without gear slippage or drift, making it ideal for real-time steering corrections.

---

## **JX PDI-4409MG — Technical Specifications**

| **Parameter** | **Specification** |
|---|---|
| **Model** | JX PDI-4409MG Coreless Metal Gear Digital Low Profile Servo |
| **Type** | Digital servo, coreless motor, metal gears |
| **Stall Torque @ 4.8 V** | ~7.8 kg·cm |
| **Stall Torque @ 6.0 V** | ~9.2 kg·cm |
| **Speed @ 4.8 V** | 0.13 s / 60° |
| **Speed @ 6.0 V** | 0.11 s / 60° |
| **Dead Band** | 2 µs |
| **Motor Type** | Coreless DC |
| **Gear Material** | Metal |
| **Bearings** | Dual ball bearings |
| **Operating Voltage** | 4.8–6.0 V DC |
| **Connector** | JR-type, ~265 mm |
| **Dimensions** | 40.5 × 20.3 × 28 mm |
| **Weight** | 44.5 g |
| **Case Material** | Aluminum mid-case |
| **Control Signal** | PWM (1520 µs neutral) |
| **Operating Angle** | ~120° mechanical |
| **Applications** | Robotics, RC cars, UAVs, actuators |
| **Manufacturer** | JX Servo Co., Ltd. |

---

## **MECHANICAL ELEMENTS**

### **1. Deep Groove Ball Bearing 684ZZ – Core Rotational Support Element**

<p align="left">
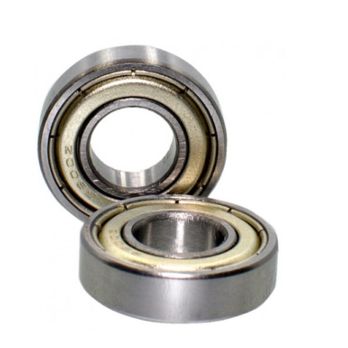
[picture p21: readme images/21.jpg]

</p>

These bearings form the **core mechanical foundation** of the robot’s motion system.  
Whenever a component rotates, pivots, or transmits torque, it is almost certainly supported by one of these bearings.

Their small size and high precision make them ideal for **compact, high-speed robotic assemblies**.

The 684ZZ bearings:

- minimize friction and vibration  
- improve drivetrain smoothness  
- increase motor efficiency  
- stabilize wheel and differential modules  
- support high‑speed rotation without deformation  

They are especially important in the robot’s **semi-spherical drivetrain**, where tight tolerances and low resistance are essential.

---

## **684ZZ Deep Groove Ball Bearing — Technical Specifications**

| **Parameter** | **Specification** |
|---|---|
| **Type** | Deep Groove Ball Bearing 684ZZ |
| **Inner Diameter (ID)** | 4 mm |
| **Outer Diameter (OD)** | 9 mm |
| **Width** | 4 mm |
| **Shield Type** | Double Metal Shield (ZZ) |
| **Material** | Chrome Steel (GCr15) |
| **Lubrication** | Pre-lubricated (high-speed grease) |
| **Dynamic Load Rating (Cr)** | ~0.68 kN |
| **Static Load Rating (Cor)** | ~0.25 kN |

---

## **2. Radial Deep-Groove Ball Bearing CX 61700 ZZ – Differential Support Bearing**

<p align="left">
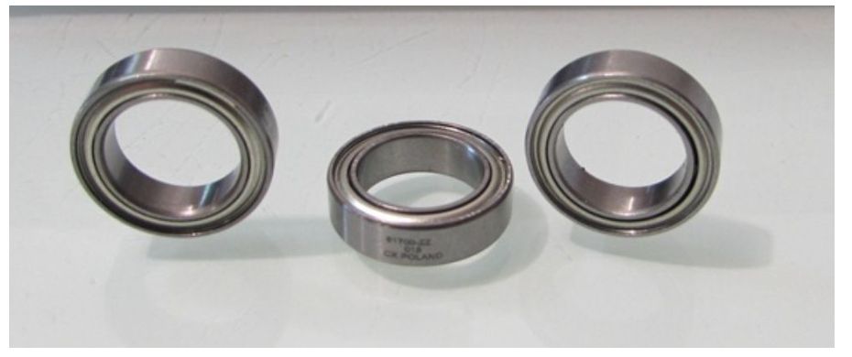
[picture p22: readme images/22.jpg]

</p>

This larger bearing was introduced after the robot’s chassis and drivetrain grew significantly compared to last year's model.  
Many earlier mechanical solutions could no longer support the **increased torque and structural loads**, especially inside the differential assembly.

In previous versions, the differential suffered from:

- instability  
- lateral play (“wobbling”)  
- misalignment under load  

because the smaller bearings were not able to secure the shaft firmly.

The **CX 61700 ZZ** solved these issues by providing:

- rigid radial alignment  
- minimal lateral movement  
- stable shaft support  
- precise low-friction rotation  

Due to **tight spatial constraints** — with the differential body and central axle sharing the same structural axis — this bearing’s **thin 4 mm profile** made it the ideal choice.  
It provided the necessary rigidity without increasing chassis width or interfering with transmission geometry.

---

## **CX 61700 ZZ Bearing — Technical Specifications**

| **Parameter** | **Specification** |
|---|---|
| **Model** | CX 61700 ZZ |
| **Type** | Radial deep-groove ball bearing, single-row |
| **Inner Diameter (d)** | 10 mm |
| **Outer Diameter (D)** | 15 mm |
| **Width (B)** | 4 mm |
| **Shield Type** | ZZ — double metal shield |
| **Material** | Chrome Steel (GCr15) |
| **Mass** | ~0.002 kg |
| **Lubrication** | Pre-lubricated (high-speed grease) |

---

## **3. Metric Mounting Screw Set – M1, M2, M2.5 (Precision Fasteners Kit)**

<p align="left">
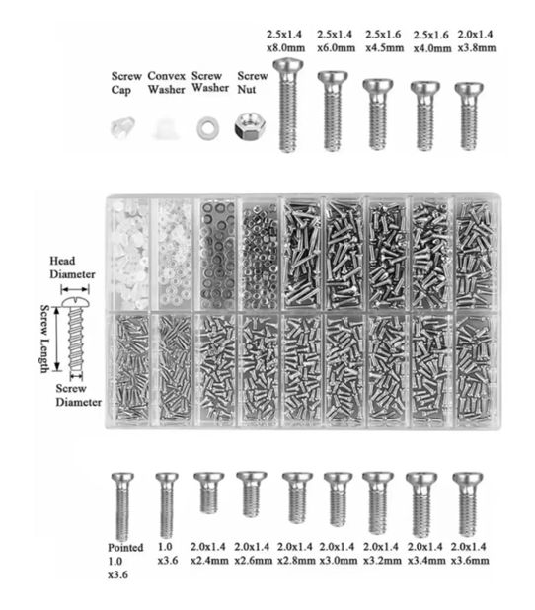
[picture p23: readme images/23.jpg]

</p>

This small hardware kit became an **unexpected turning point** in the robot’s mechanical assembly.  
Originally purchased simply to replace missing M2.5 screws for the Raspberry Pi, it revealed an entire **new design scale** — ultra‑small metric fasteners suitable for compact, high‑precision 3D‑printed assemblies.

What began as a coincidence quickly became a **design breakthrough**:

- Tiny M1–M2 screws enabled structural joints previously impossible with glue or snap‑fits  
- Allowed extremely compact mounts for sensors, linkages, and micro‑mechanisms  
- Greatly improved serviceability and component modularity  
- Gave the robot a more **professional, machine‑grade build quality**  

These miniature screws became one of the highest **cost‑to‑performance upgrades** in the entire project: inexpensive, widely available, yet transformative in what could be mechanically built at small scale.

---

## **Metric Screw Set — Technical Specifications**

| **Parameter** | **Specification** |
|---|---|
| **Type** | Metric screw assortment — M1, M2, M2.5 |
| **Material** | Carbon steel |
| **Head Style / Drive Type** | Phillips cross‑head |
| **Surface Finish** | Nickel‑plated |

---

## **4. Threaded Rod RS PRO 530‑292 – Structural Torque Transmission Element**

<p align="left">
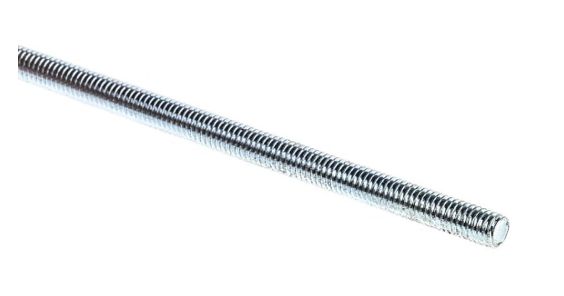
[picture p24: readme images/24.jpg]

</p>

The **RS PRO 530-292 threaded rod** serves as a rigid mechanical backbone for transmitting force and rotation across the robot’s frame.

Early prototypes suffered from **chassis flex** — even thick 3D‑printed beams would bend slightly under load.  
This caused:

- distortion in steering geometry  
- inaccurate servo feedback  
- unpredictable wheel angles  
- inconsistent turning precision  

Replacing flexible plastic connectors with a **precision-cut steel threaded rod** solved the issue completely.

This rod:

- links the servo output to the opposite-side steering assembly  
- ensures **pure torque transfer with zero angular error**  
- screws directly into 3D‑printed components  
- requires no adhesives or extra fittings  
- remains perfectly straight even under high stress  

This is critical for maintaining **precise steering alignment**, especially at high speeds.

Beyond its primary function, it opened new design possibilities — acting as a miniature structural rail for future metal‑reinforced 3D‑printed chassis concepts.

---

## **RS PRO 530-292 Threaded Rod — Technical Specifications**

| **Parameter** | **Specification** |
|---|---|
| **Model / Stock Number** | RS PRO 530-292 |
| **Product Type** | Threaded Rod |
| **Thread Size** | M3 |
| **Thread Type** | Metric, fully threaded |
| **Material** | Steel (Grade 4.6 mild steel) |
| **Surface Finish** | Zinc plated (BZP) |

---

## **5. Tire 24 × 12 Low-Profile – LEGO Part 18977**

<p align="left">
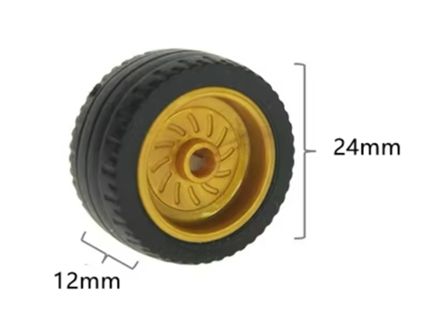
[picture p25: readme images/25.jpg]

</p>

This tire was selected because its **small radius reduces the physical envelope** of the steering assembly.  
Since each wheel in the drivetrain can rotate **up to 180°**, any increase in tire radius would significantly enlarge the clearance required for full steering articulation.

The **24 × 12 low-profile** tire offers:

- a compact wheel size  
- a wide, stable contact patch  
- excellent traction on smooth indoor surfaces  
- minimal deformation during rapid direction changes  

The uniform tread and rounded shoulders provide **predictable lateral grip**, essential for high‑precision steering corrections.  
Despite being LEGO components, their **dimensional accuracy and material consistency** make them well suited for competitive robotics.

---

## **LEGO Tire 18977 — Technical Specifications**

| **Parameter** | **Specification** |
|---|---|
| **Part Number** | 18977 |
| **Name** | Tire 24 × 12 Low Profile |
| **Material** | LEGO rubber compound (TPE-like) |
| **Color** | Black |
| **Mounting** | Press-fit on compatible LEGO rims |
| **Years Produced** | 2015 – present |
| **Notes** | Low-profile, wide footprint, excellent grip |

---

## **6. Cable System — Power and Signal Distribution**

The robot’s cabling system is designed for **stable power delivery** and **reliable data transmission** across all modules while keeping the layout clean and modular.

The main wire used is a **0.2 mm Arduino cable**, chosen for flexibility and compatibility with the Raspberry Pi GPIO.

### **Connection Types Used in the Robot**

1. **Arduino cable (main line):**  
   - primary wiring backbone  
   - connects directly to GPIO  
   - branches to secondary modules  

2. **Grove Cytron connector (4-pin, 2 mm pitch):**  
   - exclusive connection for the Cytron MD13S driver  

3. **Standard 2-pin Grove connector:**  
   - dedicated to powering the TPS61088 DC-DC boost converter  

---

## **Power Distribution Strategy**

Because the UPS HAT powers the entire system through a **single interface**, custom‑soldered branches were needed.

### **5 V Rail (GPIO pins 2 and 9)** — split into two lines:

- **Line A:** Arduino cable → Servo motor  
- **Line B:** 2‑pin Grove connector → TPS61088 boost converter  

### **Ground (GND)** — split into **three** lines:

- **GND A:** shared with 5 V servo line  
- **GND B:** for the TPS61088 module  
- **GND C:** for the 4‑pin Cytron Grove connector  

PWM and DIR pins for the Cytron driver are connected to the Raspberry Pi GPIO through **standard Arduino wiring**, ensuring stable signal levels and compatibility.

---

## **Other System Connections**

- **Camera (OV5647):** connected directly via CSI ribbon cable  
- **RPLIDAR S3:** connected via USB adapter (requires two USB ports: power + data)  
- **All remaining wiring:** standard Arduino conventions for easy modularity  

This custom system ensures:

- stable shared power from the UPS HAT  
- clean wiring layout  
- modular upgrades  
- sufficient current delivery across all components  
- prevention of overload on any single power line  

---
# PART 3: ROBOT CONSTRUCTION — Core Structure Elements

## **Introduction**

This section provides a detailed overview of every major **3D‑printed and structural component** used in the robot’s construction.  
The documentation follows a logical progression — from the **base frame**, drivetrain components, hinge and steering systems, to **wheel assemblies** and **auxiliary mounting modules**.

Each element includes:
- its **function**  
- its **relationship** with other components  
- key **engineering** or **assembly details**  

---

# **1. Frame System — Base and Structural Parts**

## **1.1. Frame Top — Sensor and Electronics Mounting Plate**

<p align="left">
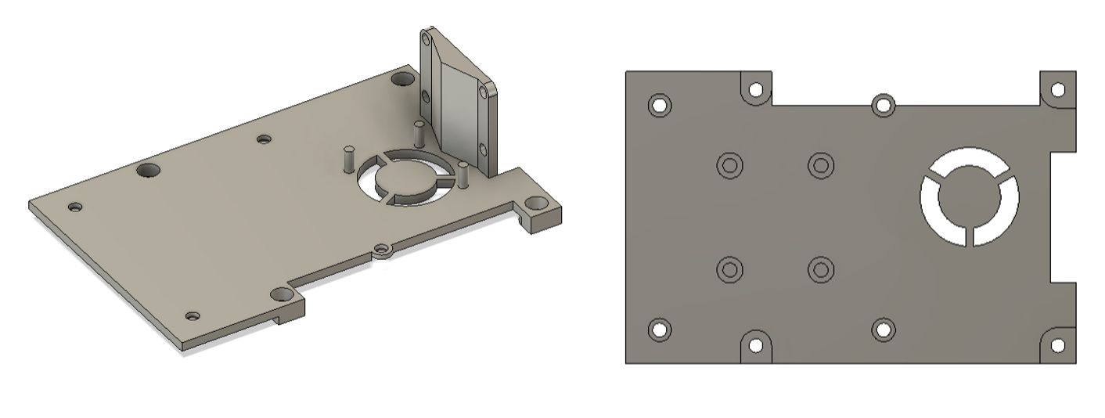
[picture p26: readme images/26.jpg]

</p>

**Function:**  
The Frame Top serves as the primary **mounting platform** for all major electronics, including the Raspberry Pi, LiDAR interface board, camera module routing, and auxiliary sensor units.  
It is the uppermost structural layer of the chassis.

**Engineering Notes:**  
- Designed with **dedicated screw points** (M2 / M2.5) for secure mounting.  
- Integrates **cable routing channels** to prevent wire interference with the drivetrain.  
- Reinforced perimeter walls provide rigidity without unnecessary weight.  
- The geometry ensures efficient heat dissipation from the Raspberry Pi and UPS HAT.  
- Alignment tabs ensure perfect fit with the Main Frame.

**Component Role:**  
Forms the stable platform that ties together the sensing layer of the robot, ensuring that IMU, camera, Raspberry Pi, and LiDAR connections remain rigid and vibration‑free.

---

## **1.2. Main Frame — Structural Base of the Robot**

<p align="left">
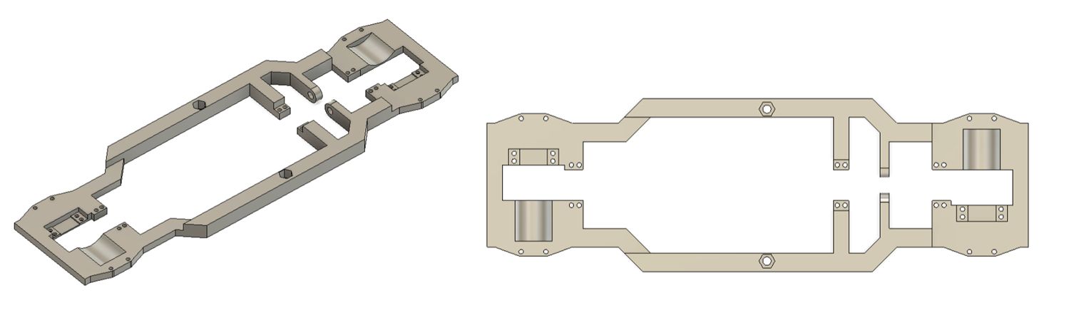
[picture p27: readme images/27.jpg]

</p>

**Function:**  
The Main Frame is the **central chassis** of the robot — the structural foundation that distributes mechanical load, supports torque transfer, and integrates all major drivetrain and steering subsystems.

**Engineering Description:**  
- 3D‑printed from **PETG** for optimal stiffness and vibration resistance.  
- Designed as a **single-piece structural body** to maximize rigidity while keeping weight low.  
- Features reinforced ribs forming a load-bearing grid beneath the drivetrain.  
- Houses mounting channels for the differential, steering hinge frames, and motor supports.  
- Provides precise alignment for the **main axle**, bearing housings, and semi‑spherical gear system.  
- Includes symmetrical geometry to maintain accurate centerline alignment — essential for LiDAR mapping stability and IMU compensation.  

**Component Role:**  
The Main Frame serves as the **mechanical backbone** of the robot, connecting the front and rear sections, transferring torque between drivetrain modules, and ensuring that steering and differential components remain perfectly aligned.

---

The **main frame** is the primary structural platform that supports all mechanical and electronic subsystems.  
It provides mounting points for the wheel assemblies, differential mechanisms, the main drive motor, and the hinge connectors for the central axle.

### **Engineering Description**
- Symmetrical layout allowing identical wheel modules at the **front and rear**.  
- Paired mounting holes at both ends ensure interchangeable assembly.  
- Cylindrical cutouts and opposing slots secure the **differential housings**.  
- Distributed micro‑connectors along the central spine support hinge and axle elements.  
- Two hexagonal cutouts function as attachment points for the rear Raspberry Pi assembly.  

### **Structural Characteristics**
- 3D‑printed with **variable thickness**:
  - **3 mm** on the main surface to improve interior clearance for motor and battery.
  - **6 mm** on reinforcement beams for additional torsional stiffness.
- Slight wheel‑axis offset ensures **full 180° wheel rotation** without contacting the frame.
- Defines the robot’s **overall geometry**, ensuring:
  - precise drivetrain alignment  
  - stable torque distribution  
  - high structural rigidity  

---

## **2. Diamond–Diamond Axle Connector**

<p align="left">
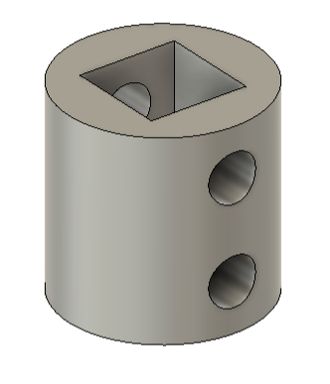
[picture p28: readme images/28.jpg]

</p>

This component serves as a **universal coupling element** for the robot’s 4 mm axles — the standard diameter used across the drivetrain due to its excellent balance of compactness and mechanical strength.

### **Engineering Description**
- Cylindrical connector body with a **square central socket** for anti-slip engagement.  
- Two perpendicular **set‑screw holes** allow firm tightening onto both shafts.  
- Ensures stable transfer of torque between:
  - the main axle  
  - the steering linkage  
  - the differential assembly  

### **Functional Role**
The connector is used to **join two separate axle segments**, enabling:
- modular assembly  
- easy maintenance  
- adjustable shaft lengths  
- secure torque transmission  

Although some other printed parts integrate similar male/female axle interfaces, this standalone connector adds **flexibility and precision** during prototyping and fine‑tuning of the drivetrain.

---

## **3. Ball Bearing Frame — Differential Support Mount**

<p align="left">
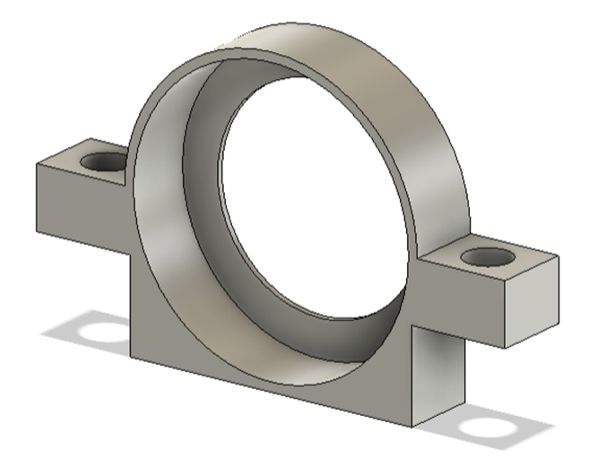
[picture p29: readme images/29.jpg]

</p>

This component functions as a **structural adapter** for mounting a standard ball bearing onto the main frame near the differential assembly.  
It ensures **stable fixation of the main axle**, which passes directly through the bearing, allowing smooth and perfectly aligned rotation under load.

### **Engineering Description**
- Includes two **lateral mounting holes**, compatible with the robot’s standard metric screw set.  
- Designed for precise positioning of the bearing relative to the **differential gears**.  
- Distributes perpendicular forces generated during torque splitting, preventing axle bending or misalignment.  
- Provides a rigid stabilization point that locks the main axle’s position during high-speed movement.

### **Functional Role**
The Ball Bearing Frame is essential for drivetrain stability.  
The differential generates significant **lateral and vertical forces**, and this mount ensures the axle remains:

- rigid  
- centered  
- vibration-free  
- aligned with the drivetrain geometry  

Without this frame, the differential assembly would experience wobble, decreasing efficiency and increasing gear wear.

---

## **4. Ball Bearing Frame with Tube — Axle Protection and Support Mount**

<p align="left">
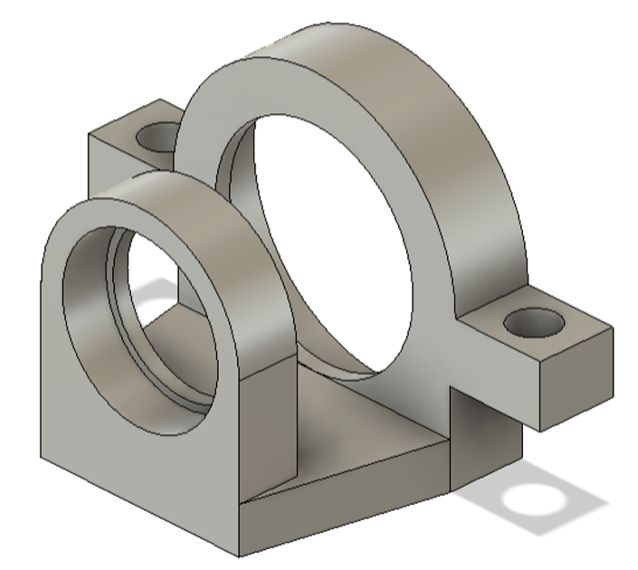
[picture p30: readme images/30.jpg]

</p>

This enhanced version of the standard ball bearing frame incorporates a **cylindrical tube holder** designed to support a lightweight protective tube surrounding the main axle.  
The tube acts simultaneously as:

- a **mechanical guard**, preventing accidental contact between the rotating axle and sensitive components (e.g., battery pack), and  
- a **stabilizing sleeve**, reducing lateral oscillation during high‑speed movement.

### **Engineering Description**
- Designed to hold a thin protective tube in perfect alignment with the **bearing axis**.  
- Maintains the axle’s central position between the differential and the primary bearing mount.  
- Prevents the axle from drifting outward under torque or impacts.  
- Printed with reinforced walls to withstand continuous dynamic loading.  
- Secured to the main frame using **two standard metric screw holes**, identical to the mounting pattern of the standard bearing frame.

### **Functional Role**
Without this component, the main axle would lack one of its critical lateral support points, increasing the risk of:

- misalignment  
- rotation-induced vibration  
- drivetrain inefficiency  
- full detachment under sudden torque spikes  

This frame ensures that the axle remains **perfectly centered, protected, and stable**, even under high mechanical load.

---

## **5. Main Axle and Support Structure**

<p align="left">
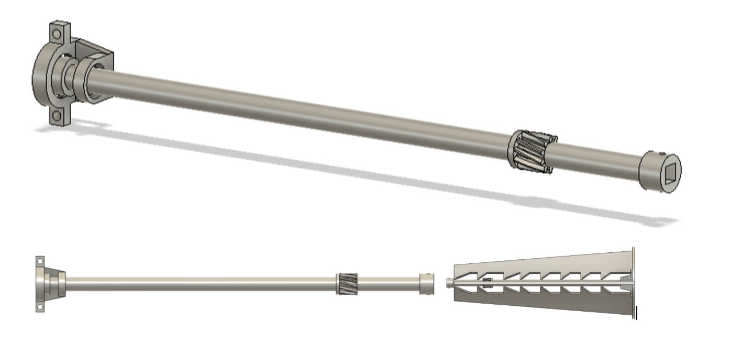
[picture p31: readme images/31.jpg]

</p>

The **main axle** is the central mechanical element responsible for transmitting rotational torque from the motor to both differentials.  
It spans the entire length of the robot, connecting the **motor-side drive gear** to the **opposite differential assembly**, forming the backbone of the drivetrain.

### **Engineering Description**
This part integrates multiple functional elements into a **single 3D‑printed structure**:

- A rigid torque-transfer shaft  
- An embedded bearing frame  
- A protective stabilization tube  
- Internal supports printed in-place  

Because of its complexity, the axle is printed **vertically**, which requires:

- a **controlled print pause** to insert a ball bearing near the motor interface  
- specialized support towers to prevent shaft deformation  
- precise alignment to ensure smooth rotation under load  

These internal supports are visible in the model and help maintain **perfect axial geometry**, especially around the gear teeth and bearing interface.

### **Functional Role**
The final printed axle is:

- rigid  
- lightweight  
- vibration-resistant  
- capable of transferring torque with high precision  

It ensures stable operation of both differentials and preserves drivetrain alignment even under long-term mechanical stress.

---

## **6. Hinge Frame — Robot Side**

<p align="left">
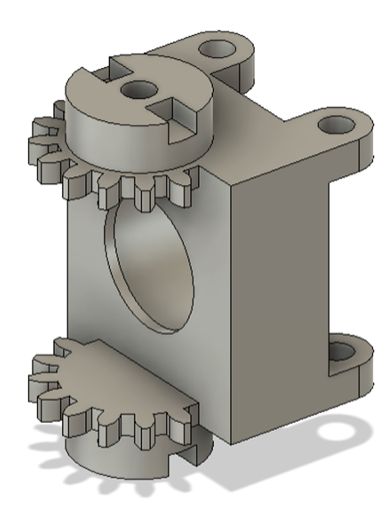
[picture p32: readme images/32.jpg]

</p>

This component forms one half of the wheel rotation mechanism and attaches directly to the main frame of the robot.  
It includes **four mounting contact points** for structural fixation and a **central bearing housing** to ensure precise rotational alignment of the hinge assembly.  
Two **cylindrical pins** extend outward from the frame to connect with the opposite hinge half, creating a stable pivot joint.

Adjacent to the pins are **two integrated gears** that synchronize the movement of both hinge sides, ensuring coordinated rotation during steering.  
The component provides both **mechanical support** and **transmission alignment**, allowing the wheel assembly to articulate smoothly while maintaining consistent torque transfer through the hinge system.

---

## **7. Hinge Frame — Wheel Side**

<p align="left">
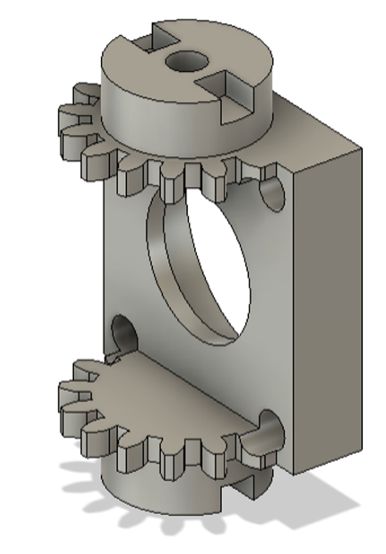
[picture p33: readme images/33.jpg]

</p>

This component is a **compact counterpart** to the robot-side hinge frame and is engineered to minimize the total length of the steering mechanism while preserving full rotation clearance for the wheel module.

### **Engineering Description**
- Contains a **partial bearing housing**, designed so that **one half of the ball bearing seats in this frame**, while the remaining half is enclosed by the Robot-Side hinge.  
  This reduces assembly thickness and ensures tight axial alignment.
- The hinge geometry is shortened to create space for **full 180° wheel rotation**.
- Two **integrated gears** are positioned with a **one‑tooth offset** relative to the robot-side hinge frame.  
  This prevents interference and ensures smooth meshing during synchronized articulation.
- The structural body includes precise mounting contours that connect directly to the wheel module.

### **Functional Role**
The Wheel-Side Hinge Frame provides:

- **Accurate mechanical coupling** between the wheel and the chassis  
- **Stable rotational alignment** through the shared bearing system  
- **Synchronized steering movement** via the paired gear system  
- A compact form that maintains maneuverability without sacrificing structural rigidity  

This part is essential for delivering consistent steering response and for enabling the robot’s highly compact wheel rotation system.

---

## **8. Hinge Frame Cover**

<p align="left">
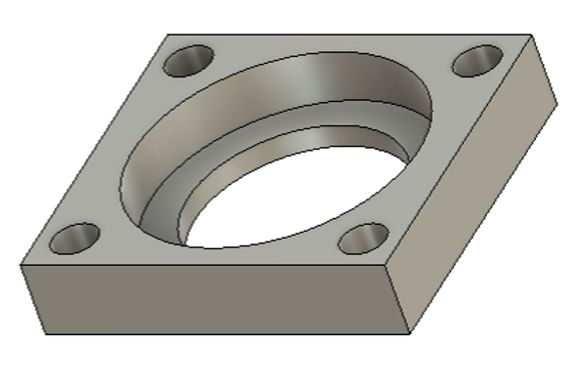
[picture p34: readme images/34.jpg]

</p>

This component attaches to the **wheel-side hinge frame** using four screws and secures the **outer half of the ball bearing** within the hinge assembly.  
Its primary function is to **lock the bearing in place**, preventing any axial movement or loosening during high‑speed wheel rotation.

### **Engineering Description**
- Fastens directly to the Wheel-Side hinge via **four mounting screws**.  
- Encloses the second half of the bearing, completing the hinge’s rotational chamber.  
- Maintains **precise axial alignment**, ensuring the bearing remains centered under load.  
- Adds **structural rigidity** to the hinge assembly by bracing its outer perimeter.  
- Designed with minimal thickness to reduce bulk while retaining high-strength support.

### **Functional Role**
The Hinge Frame Cover is essential for:

- Securing the bearing against outward displacement  
- Preserving smooth, consistent hinge rotation  
- Preventing vibration or misalignment during steering  
- Increasing durability of the entire wheel‑rotation subsystem  

By closing the hinge from the external side, it finalizes the complete bearing enclosure and ensures long-term stability during robot operation.

---

## **9. Hinge Connector and Hinge Arm (Left & Right)**

<p align="left">
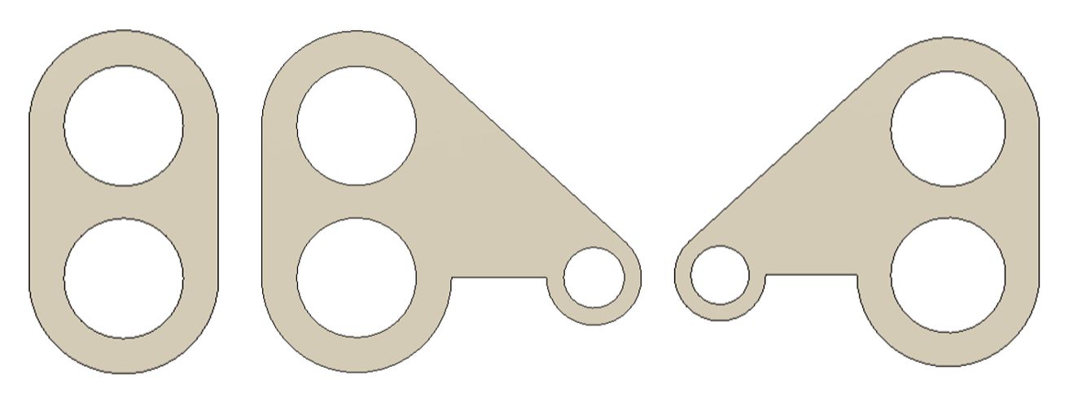
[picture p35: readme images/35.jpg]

</p>

These components link the two halves of the hinge assembly from both sides, ensuring structural stability, correct spacing, and synchronized steering motion.

### **Engineering Description**

- The **Hinge Connector** forms the primary mechanical bridge between the Robot-Side and Wheel-Side hinge frames.  
  It prevents separation of the hinge halves and maintains the correct axial spacing needed for smooth rotation.

- The **Hinge Arms (Left & Right)** are modified extensions of the connector design.  
  Each arm includes **additional mounting points** used to attach the steering linkage that transfers motion from the servo system.

- The arms connect directly to the **Wheel-Side hinge frame**, enabling full **180° wheel rotation** without interference.  
- The L/R mirrored versions ensure perfect mechanical symmetry and balanced steering behavior across the robot.

### **Functional Role**

Together, these parts:

- Complete the mechanical hinge loop  
- Maintain rigid structural coupling between hinge halves  
- Provide mounting interfaces for steering linkages  
- Ensure synchronized, precise steering geometry across both sides  
- Allow smooth articulation of each wheel module under dynamic loads  

This tri-component system is essential for reliable turn mechanics, symmetry, and structural durability.

---

## **10. Hinge Cap and Hinge Cap (Gear)**

<p align="left">
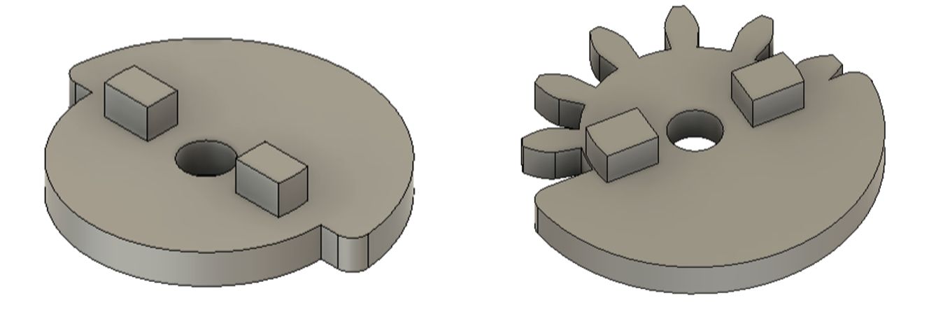
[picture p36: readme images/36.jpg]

</p>
These components secure the hinge connectors in place, preventing them from slipping off the alignment pins and ensuring long-term mechanical reliability of the hinge assembly.

### **Engineering Description**

- The **standard Hinge Cap** mounts directly to the hinge frame using screws.  
  Its purpose is to lock the hinge connector on the pivot pins, preventing axial displacement during wheel articulation.

- The **Hinge Cap (Gear)** is a reinforced variation featuring an **integrated tooth profile**.  
  This profile provides optional mechanical engagement and additional resistance to lateral forces — especially beneficial when wheels experience side impacts or vibration during high‑speed operation.

### **Assembly Considerations**

Proper torque must be applied during installation:

- **Over‑tightening** increases rotational friction, restricting hinge movement and causing steering lag.  
- **Under‑tightening** allows unwanted play in the hinge, reducing steering accuracy and increasing wear.

Achieving the correct torque balance is essential for maintaining:

- Smooth, low‑friction rotation  
- Stable wheel alignment  
- Consistent steering response  
- Long-term durability of the hinge system  

---

## **11. Sun Gear Long — Wheel Rotation and Torque Transfer Element**

<p align="left">
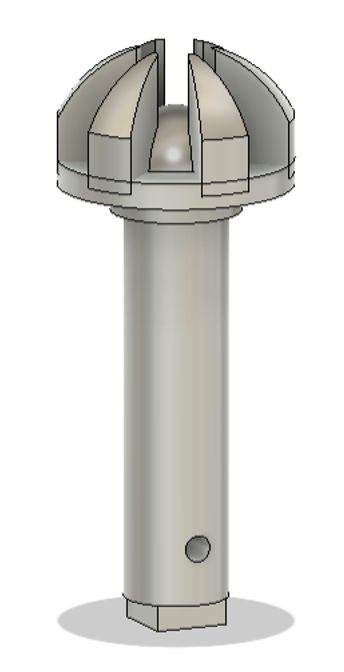
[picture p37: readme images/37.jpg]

</p>

This component makes possible the full **180° steering rotation** of the wheel using a patented **semi-spherical gear mechanism**.  
Its geometry is optimized for both strength and smooth operation, enabling reliable power transmission through the steering axis.

### **Engineering Description**
- Features **reinforced gear teeth** shaped to maintain stable engagement even at extreme articulation angles.  
- The **central rounded hub** increases rigidity and prevents deformation under torque load.  
- An **extended shaft** allows deep insertion into the wheel housing, creating a strong and stable mechanical interface.  
- Designed to align precisely with the hinge structure and differential elements for uninterrupted motion.

### **Development & Iteration**
This gear underwent several experimental revisions to achieve:

- Smooth engagement at wide articulation angles  
- High resistance to bending loads  
- Self-supporting internal strength  
- Perfect compatibility with the semi-spherical drivetrain geometry  

### **Functional Role**
The Sun Gear Long is essential for:

- Transmitting rotational torque from the drivetrain into the wheel module  
- Maintaining alignment within the hinge assembly  
- Enabling articulated motion without power loss  
- Ensuring smooth, predictable wheel rotation during steering  

Its robust, high-precision form makes it one of the key elements of the robot’s semi-spherical steering and torque-transfer mechanism.

---

## **12. Sun Gear Short — Modular Torque Transmission Node**

<p align="left">
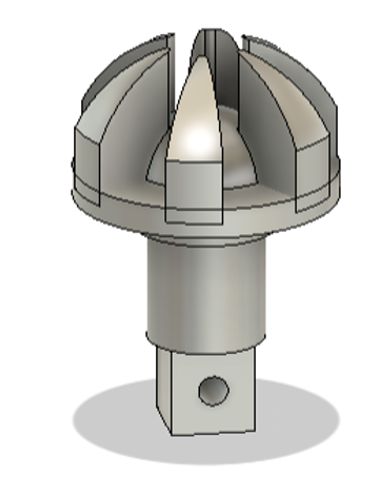
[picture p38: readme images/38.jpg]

</p>

The Sun Gear Short operates on the same mechanical principle as the **Sun Gear Long**, but features a **significantly shortened shaft** tailored for modular integration within the drivetrain system.

### **Engineering Description**
- Designed to interface directly with the **Diamond–Diamond Axle Connector**, enabling torque transmission between interchangeable drivetrain modules.  
- The shortened shaft minimizes spatial footprint without reducing alignment accuracy or structural strength.  
- Maintains a **rounded central hub**, ensuring rigidity under load and preventing deformation during high‑torque operation.  
- Compact geometry allows placement in areas where full-length gears cannot fit, while still ensuring proper engagement with the semi-spherical gear system.

### **Functional Role**
The Sun Gear Short is optimized for:

- **Modular drivetrain configurations**  
- **Quick replacement** during tuning or maintenance  
- **Precise torque transfer** through compact assembly zones  
- **Alignment stability** in multi-element gear networks  

Its efficient design ensures that the drivetrain remains flexible, serviceable, and mechanically robust even in confined structural regions.

---

## **13. Wheel Assembly — LEGO-Compatible Low-Profile Drive Interface**

<p align="left">
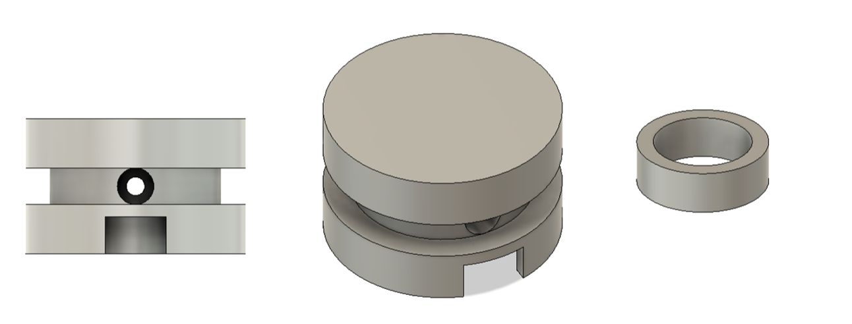
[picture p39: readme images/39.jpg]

</p>

This wheel serves as the primary mechanical interface between the robot’s drivetrain and the LEGO tire system, providing a **secure, precise, and modular** connection fully compatible with LEGO low-profile tires.

### **Engineering Description**
- The wheel hub includes a **central removable ring insert**, designed to:
  - reduce overall print height  
  - minimize support material usage  
  - improve circular dimensional accuracy  
  - strengthen the contact zone between the axle and the tire  

- The ring insert is printed separately to avoid distortion in tall cylindrical features, ensuring **high tolerances** where the tire attaches.

- The outer diameter strictly follows the **LEGO 24 × 12 Low Profile Tire standard**, enabling a perfect press-fit attachment.

- The wheel geometry is tuned to maintain the exact spacing required for:
  - torque transmission  
  - steering articulation  
  - clearance between the tire and structural frame  

### **Functional Role**
This wheel assembly ensures:

- **Reliable torque transfer** from the axle to the tire  
- **Stable alignment** during high-speed rotation  
- **Modular compatibility** with LEGO components  
- **Quick replacement** during testing or repairs  

Because of its hybrid printed–LEGO design, it combines precise engineering with the flexibility of modular robotics.

---

## **14. Hinge Support — Bearing Retention and Structural Reinforcement**

<p align="left">
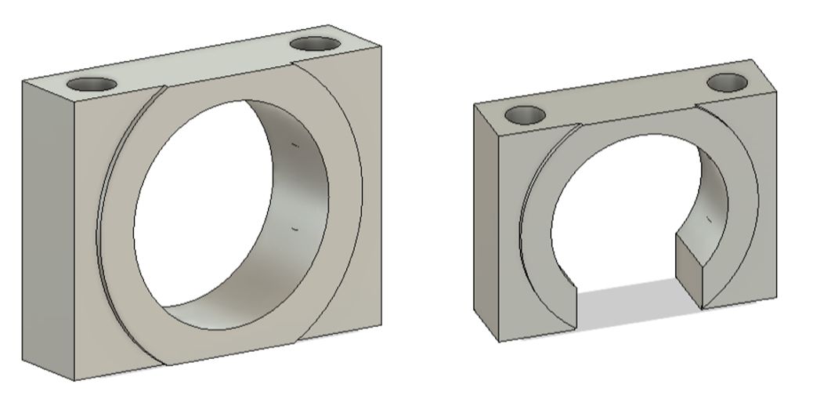
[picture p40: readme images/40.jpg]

</p>

The hinge support components are designed to **securely hold the ball bearing** inside the Robot-Side hinge frame.  
Their primary function is to ensure **accurate bearing alignment** and prevent any axial displacement during wheel rotation.

### **Engineering Description**
- Provides a rigid mounting enclosure for the ball bearing, allowing smooth and stable hinge articulation.  
- Eliminates the need for complex “print‑in‑place” bearing traps, simplifying assembly and improving reliability.  
- Transfers structural loads from the steering mechanism into the chassis without deformation.  
- Strengthens the hinge’s side walls, preventing flex under torque.

### **Open Variation**
An alternative “open” version includes a **cutout** that grants screwdriver access to an internal screw deep inside the hinge assembly.  
This design:

- improves serviceability  
- enables fast disassembly  
- avoids removing the entire hinge module  

### **Functional Role**
The hinge support ensures:

- secure bearing retention  
- rigid steering geometry  
- reduced vibration during articulation  
- precise axle alignment across the hinge assembly  

It is an essential reinforcement element that maintains long‑term reliability of the robot’s steering system.

---

## **15. Differential — Torque Distribution and Height Optimization**

<p align="left">

</p>

The differential is built around a single hypoid gear, enabling the main drive axle to sit **4 mm lower** than the wheel axis — a structural decision that significantly reduces the overall height of the robot. This compact design contributes to a lower center of gravity and improved stability during motion.

The differential casing is laterally offset due to the geometry of the hypoid gear, but this shift does not interfere with performance. Beneath the gear sits a connector mount for a **large ball bearing**, providing stability under rotational load.

Functionally, the differential plays a crucial role in torque distribution — it ensures both wheels receive appropriate power during turns. This is essential because each wheel follows its own path radius, and without differential control, one wheel would slip or drag.  
The combination of precision gearing, ball bearing support, and structural alignment allows this differential to deliver **smooth, balanced power transfer** across the drivetrain.

---

## 17. Differential Pin — Secondary Bearing Coupler

<p align="left">

</p>

The Differential Pin is the companion component to the main differential housing, serving as the **rear coupling interface** that connects the differential assembly to the large ball bearing. It ensures that the rotational load from the hypoid gear is evenly distributed and transmitted to the support structure, maintaining stability under torque stress.

Its circular flange with **three mounting holes** allows secure attachment to the differential body while aligning precisely with the bearing mount.  
The pin’s centered bore provides a tight fit for the axle shaft, ensuring **smooth, low-friction rotation**.

Though small, this part is essential for maintaining mechanical precision in the robot’s drivetrain — without it, the entire differential system would lose its axial support and alignment.

---

## 18. Differential Sun Gear (Long and Short) — Angular Torque Transfer Pair

<p align="left">

</p>

The differential sun gears form the active core of the hypoid transmission system, responsible for translating motor torque into balanced rotational output for both wheels. Both gears share identical tooth geometry, optimized for angular torque transfer at **45°**, but differ in axle configuration to accommodate the offset differential housing.

### Long Version
The long sun gear features an **extended cylindrical shaft** that passes through the differential body, ensuring stable alignment and continuous torque transfer.  
It connects to the wheel hinge via a **diamond–diamond connector**, allowing secure coupling between the drivetrain and steering assembly.

### Short Version
The short sun gear includes a **built‑in square diamond connector** instead of a shaft.  
This compact interface allows direct attachment to the hinge mechanism without additional adapters, minimizing space usage and increasing structural rigidity.

Together, these two gears form a synchronized torque‑distribution pair, enabling smooth angular power transfer across the differential assembly.

---

## 19. Differential Planetary Pinion — Core Gear of the Torque Balance System

<p align="left">

</p>

This component is one of the key elements that allows the differential to function correctly.  
It features the same bevel gear profile as the previously described sun gears but serves a different mechanical role — it is **mounted inside the differential housing** and acts as the central balancing element between the two sun gears.

The planetary pinion transfers rotational motion between the sun gears, ensuring **balanced torque distribution** when the robot turns or when one wheel experiences resistance.

### Attachment & Mechanical Behavior
- Mounted via a **precision-fit screw connection**.  
- The gear rotates around its own pin and is subjected to significant lateral pressure.  
- A **partially threaded 2.5–2.6 mm screw** is used:  
  - Only the tip engages the thread.  
  - The smooth shaft portion allows free, low-friction rotation.  
- Over-tightening must be avoided, as excess pressure increases friction and restricts movement.

### Functional Importance
This gear is essential to proper differential operation.  
Without the planetary pinion:

- torque distribution between wheels would be uneven  
- turning stability would be compromised  
- drivetrain smoothness would degrade  
- wheel-slip during curves or terrain transitions would increase  

It is the core element that enables true differential action.

---

## 20. Big Ball Bearing Frame — Main Bearing Mount and Structural Adapter

<p align="left">

</p>

This component serves as the primary mount for the robot’s **large ball bearing**, acting as a structural adapter between the bearing and the chassis.  
It ensures **precise drivetrain alignment** and provides a rigid interface for torque transfer.

Two identical units are used — positioned on both sides of the main differential — to secure the bearing and maintain **perfectly parallel geometry** across the drivetrain structure.

### Engineering Description
- Designed to hold the large bearing **flush inside the frame**, preventing axial or lateral shifting.  
- Ensures that rotational forces from the differential are evenly distributed across the mount.  
- Compact spacing in this section requires **short M2.4 or M2.6 screws** for fastening.  
- Geometry is optimized for both **strength and dimensional precision**, ensuring long-term mechanical stability.

---

## 21. Hypoid Pinion — Drive-to-Differential Connector

<p align="left">

</p>

This gear connects the main axle to the differential, forming one half of the **hypoid gear pair** that transfers motor torque at an offset angle.  
The pinion ensures **smooth rotation** and **precise tooth contact** with its mating gear, delivering consistent torque across the drivetrain.

### Engineering Description
- Forms the angled drive interface between the motor-driven axle and the differential input.  
- Maintains stable contact geometry with the hypoid sun gear under dynamic load.  
- Geometry was **manually modeled and tuned**, since no automated generation tool exists for this exact configuration.  
- Parametric values were first produced using an online bevel/hypoid gear calculator, then rebuilt in **Blender**, and finally aligned and tested in **Fusion 360**.

### Development Effort
Each gear pair required:
- **20–40 minutes** of manual modeling  
- Multiple curvature and contact-angle iterations  
- Fine adjustments to tooth shape, root clearance, and surface alignment  

This made the hypoid pinion one of the **most technically refined and time‑intensive elements** in the entire drivetrain.

---

## 22. Frame Forward — Servo and Front Assembly Mount

<p align="left">

</p>

The forward frame serves as the main **front mounting plate** of the robot, connecting the **servo motor**, the **wheel hinge assemblies**, and the **differential housing**. It also provides the **front attachment points for the Raspberry Pi**, with two dedicated holes positioned near the rear edge of the plate.

A **rectangular center cutout** allows free rotation of the driving mechanism while reducing overall weight and material usage.  
The geometry is reinforced around the servo mount area to maintain structural rigidity, while still providing adequate clearance for gear movement.

---

## 23. Servo Pin — Compact Servo Retention Plate

<p align="left">

</p>

The servo pin is a small mechanical clamp used to secure the servo motor within the Frame Forward assembly.  
It allows the servo to be held firmly using **smaller, lightweight screws** instead of the large hardware typically included in servo kits — reducing overall mass and mechanical strain on the printed frame.

### Engineering Description
- Features a **dual‑slotted design**, enabling fast installation or removal of the servo without needing to disassemble the entire front mount.  
- Provides firm lateral compression around the servo tabs, preventing micro‑shifts during high‑load steering movements.  
- Designed to distribute clamping pressure evenly, protecting both the printed frame and the servo housing from stress or cracking.  

### Functional Role
Despite its compact size, the servo pin is essential for:
- Maintaining precise servo alignment  
- Preventing rotational or lateral motion during wheel articulation  
- Ensuring consistent steering geometry under dynamic loads  

Its minimalist structure makes it both **lightweight and highly reliable**, optimized for frequent assembly cycles during testing and tuning.

---

## 24. Servo Arm — Dual-Link Steering Transmission Lever

<p align="left">

</p>
The servo arm connects directly to the output shaft of the steering servo and performs **two critical steering functions**:

1. The **short forward link** connects to the front hinge steering mechanism, enabling precise directional control of the front wheels.  
2. The **longer reinforced rear link** transfers rotational torque across the robot to the opposite side, synchronizing left–right wheel articulation.

### Engineering Description
- Features a **central gear interface** designed to securely mate with the servo spline, eliminating slippage during high‑torque operation.  
- Constructed with an **asymmetrical geometry** that provides mechanical leverage while avoiding interference with nearby frame components.  
- Allows smooth **180° steering rotation** without collisions or structural obstruction.  
- Reinforced sections ensure rigidity during rapid articulation and high‑force maneuvers.

### Functional Role
The servo arm ensures:
- Synchronized wheel steering across the entire robot  
- Stable, predictable motion transfer  
- High precision in angle control  
- Reliable performance under dynamic load  

Its dual‑link configuration makes it one of the most important elements of the steering transmission system.

---

## 25. Turn Axle Connector — Embedded Joint Interface

<p align="left">

</p>

The Turn Axle Connector serves as the mechanical interface for attaching the metal rod (RS PRO 530-292).  
It is designed as a **print‑in‑place component**, meaning the 3D printer must pause mid‑process to insert a secondary mechanical element — such as the servo arm or the turn geared liftarm.

Once the insert is placed, printing resumes, encapsulating the element inside the connector and forming a **functional rotational hinge**.

### Engineering Description
- Designed to hold the **M3 metal rod** securely for torque transmission.  
- Relies on a controlled print pause to embed the secondary component at the correct layer height.  
- The insert must sit **exactly above the active layer** to avoid fusing while still being locked into place by subsequent layers.  
- Print‑in‑place geometry guarantees perfect alignment of the hinge and eliminates the need for screws or external mounts.  
- Greatly increases long‑term durability and precision of the turning mechanism.

### Functional Role
The Turn Axle Connector provides:
- A rigid and precise hinge connection  
- Accurate alignment for steering joints  
- High reliability due to fused‑structure architecture  
- Reduced mechanical play during steering motion  

This connector is one of the most assembly‑sensitive parts of the robot, requiring exact print timing and correct insert placement.

---

## 26. Turn Geared Liftarm — Direction Inversion and Torque Stabilization Link

<p align="left">

</p>

The Turn Geared Liftarm serves as the rear counterpart to the servo arm and is specifically engineered to **invert the steering direction** between the front and rear wheel systems.  
In this robot’s geometry, the front and back steering assemblies must rotate in **opposite directions** to maintain coordinated turning.  
This liftarm enables that inversion.

### Engineering Description
- Features a **compact integrated gear section** engineered for maximum surface engagement.  
- Improved tooth profile increases load tolerance and reduces bending — addressing weaknesses found in earlier iterations.  
- Provides smooth meshing with minimal friction, even under high steering loads.  
- Interfaces directly with the **metal rod (RS PRO 530-292)**, converting its rotational or linear motion into synchronized articulation for the opposite hinge assembly.  
- Reinforced structure ensures rigidity during fast directional changes.

### Functional Role
The Turn Geared Liftarm ensures:
- Accurate **direction inversion** between front and rear steering  
- Stable torque transfer across the chassis  
- Consistent and synchronized wheel articulation  
- High durability during repeated high-speed steering cycles  

This component is critical for achieving symmetric, coordinated steering across the robot’s drivetrain.

---

## 27. Turn Geared Liftarm Small — Reverse Gear Link for Steering Mechanism

<p align="left">

</p>
This smaller version of the Turn Geared Liftarm transfers and redirects rotational motion directly into the steering hinge assembly.  
Its gear orientation is intentionally **reversed** relative to the main liftarm, ensuring correct steering direction when paired with the servo‑driven linkage.

### Engineering Description
- Compact gear profile designed for tight mechanical spaces.  
- Reverse tooth orientation ensures correct motion phase relative to the primary liftarm.  
- Includes a **cutout along the beam** to prevent interference with neighboring components during articulation.  
- Interfaces cleanly with the hinge system to deliver precise steering adjustments.  
- Optimized to maintain smooth gear meshing even under dynamic steering loads.

### Functional Role
This component provides:
- Direction-corrective gear engagement  
- Smooth rotational transfer to the hinge joint  
- Low-friction operation within limited space  
- Structural stability for the steering mechanism  

Its compactness and reversed gear geometry make it a crucial link in achieving coordinated steering motion across the robot.

---

## 28. Turn Gear Pin — Retention and Stabilization Component

<p align="left">

</p>

The Turn Gear Pin secures the **Turn Geared Liftarm** and **Turn Geared Liftarm Small** in place, preventing them from slipping out of alignment during operation.  
It reinforces the axle connection, reducing bending and ensuring **smooth, consistent gear engagement** under torque.

### Engineering Description
- Acts as a **locking pin** that prevents axial movement of the liftarms.  
- Strengthens the turning mechanism by stabilizing the rotational joint.  
- Ensures proper alignment of the gear teeth throughout the steering cycle.  
- Helps distribute mechanical stress evenly across the turning assembly.  
- Prevents long-term degradation of steering precision caused by gear flex.

### Functional Role
Without the Turn Gear Pin:
- The liftarms would drift out of alignment  
- Steering accuracy would degrade over time  
- Gear meshing would become inconsistent  
- Axial play would increase, causing jitter and torque loss  

The pin is a small but essential structural element in the servo-driven steering system.

---

## 29. Turn Liftarm Set — Front, Back, and Universal Steering Connectors

<p align="left">

</p>

The Turn Liftarm components form the mechanical link between the **servo-driven rotation** (via the Turn Geared Liftarm system) and the **Wheel Hinge assemblies**, translating servo motion into synchronized wheel steering.

Each variant is designed to handle specific geometric and structural constraints inside the chassis:

### • Turn Liftarm Front
- Connects directly to the **front steering hinges**.  
- Features a **longer, reinforced pin** to absorb sharp servo movements without deformation.  
- Provides optimal leverage for the front steering geometry.

### • Turn Liftarm Back
- Designed for the **rear steering assembly**, where rotation is **inverted**.  
- Pin position is shifted closer to the chassis center to align with the reversed kinematic path.  
- Ensures symmetry and synchronized response with the front steering system.

### • Turn Liftarm Universal
- A flexible connector variant compatible with **either side** of the chassis.  
- Includes a dedicated **clearance cutout** allowing it to fit under the differential housing.  
- Prevents collisions during extreme articulation angles.

### Functional Role
Together, the three liftarms ensure:

- Consistent torque transmission  
- Perfect synchronization of front and rear steering  
- Smooth, precise articulation during high-speed maneuvers  
- Compatibility with compact chassis geometry  

---

## 30. Turn Liftarm Pin

<p align="left">

</p>

Originally designed to secure the Turn Liftarm assemblies, this component now primarily serves a **compensating and decorative role** within the turning mechanism.  
With the introduction of the **Turn Liftarm Universal**, its structural importance decreased.

### Engineering Description
- Functions as a **spacer**, ensuring that screws tighten correctly without applying excessive pressure to nearby printed components.  
- Maintains clean mechanical spacing between the Turn Liftarm structures.  
- Prevents screw over‑tightening, which could deform surrounding parts or restrict motion.  
- Provides minor stabilization but no longer carries significant load.

### Functional Role
The Turn Liftarm Pin now ensures:
- Proper screw tension  
- Safe clearance between rotating components  
- A clean, finished fit for the turn assembly  

While no longer essential for structural strength, it contributes to the reliability and longevity of the assembly.

---

## 31. Frame Back — Rear Structural Base and Motor Mount Interface

<p align="left">

</p>

The rear frame serves as the primary structural support for the **drive system**.  
It houses the **main DC motor**, provides mounting points for both the **Turn Geared Liftarm mechanisms** (standard and small variants), and includes a dedicated cutout for the **differential assembly**, mirroring the geometry of the main and forward frame structures.

### Engineering Description
- Contains a **central slot** designed to securely hold the motor mount, ensuring proper torque transfer into the drivetrain.  
- Two **extended upper arms** reinforce the rear structure and act as mounting points for the Raspberry Pi, improving overall rigidity and alignment accuracy.  
- Side mounting points accommodate both types of Turn Geared Liftarms, enabling smooth steering synchronization between the front and rear assemblies.  
- Rear geometry mirrors the forward and main frames, ensuring consistent spacing and mechanical compatibility across the chassis.

### Functional Role
The Frame Back provides:
- Secure housing for the DC motor  
- Structural reinforcement for the drivetrain  
- Consistent alignment across the robot’s frame  
- Reliable mounting for steering and differential components  

It is one of the central load‑bearing elements in the robot’s architecture.

---

## 32. Motor Mount — Structural Interface for Power Transmission

<p align="left">

</p>

The motor mount serves as the central connector between the **main DC motor**, the **rear frame**, and the **main axle system**.  
It is engineered to ensure precise alignment, stable torque transmission, and reliable support for the drivetrain during high‑load operation.

### Engineering Description
- Features **three mounting holes** arranged in a triangular pattern to secure the motor firmly and prevent rotational slip.  
- Includes **grooved lower supports** that align perfectly with the Rear Frame, locking the motor mount into its correct structural position.  
- A large **central opening** allows the motor gear to pass through and engage the drivetrain without obstruction.  
- Two lower extensions interface with the Main Frame, slightly lifting the rear assembly to isolate the motor from wheel load and reduce vibration transfer.  
- A **dedicated internal slot** stabilizes the motor gear and its pin.  
- A **lateral cutout** provides screwdriver access for easy assembly and maintenance.  
- The mount also covers the front of the motor, concealing oil residue and improving overall appearance.

### Functional Role
The motor mount:
- Provides rigid and accurate positioning of the main DC motor  
- Ensures proper meshing between the motor gear and the drivetrain  
- Transmits torque from the motor to the main axle  
- Reduces stress on the motor by isolating wheel and frame loads  
- Enhances structural rigidity and visual cleanliness of the robot  

It is one of the key structural and functional elements ensuring efficient and stable drivetrain operation.

---

## 33. Motor Gear — Main Power Transfer Gear

<p align="left">

</p>

The motor gear directly transmits rotation from the **main DC motor** to the **main axle**.  
During printing, the process is **paused to insert a ball bearing** inside the gear — a print‑in‑place technique that ensures smooth, high‑speed rotation with minimal vibration and reduced heat buildup.

### Engineering Description
- The **inner bore** is precisely matched to the motor shaft for a tight, slip‑free fit.  
- The **outer gear teeth** are angled to engage the hypoid gear on the main axle with maximum contact efficiency.  
- Designed for **efficient torque transfer** even at high rotational loads.  
- Print‑in‑place bearing integration improves:
  - rotational stability  
  - gear longevity  
  - thermal performance  
  - resistance to wobble at speed  

### Functional Role
This motor gear:
- Transmits all motor torque into the drivetrain  
- Maintains perfect alignment with the hypoid system  
- Ensures quiet, vibration‑free operation  
- Enables smooth acceleration and rapid directional transitions  

It is one of the most mechanically demanding printed components in the drivetrain.

---

## 34. Motor Gear Pin

<p align="left">

</p>

This small structural element secures the **motor gear** to the **motor mount** using a single precision screw.  
Despite its minimal size, it plays a critical role in maintaining perfect alignment between the gear and the motor shaft, preventing slippage during **high‑torque operation**.

Its precise geometry ensures that the motor gear remains locked in its correct axial position, guaranteeing stable and reliable torque transfer throughout the drivetrain.

---

## 35. Motor Driver Module — Custom Expansion Bay Integration

<p align="left">

</p>

The chassis of this robot includes modular side bays designed for adding custom hardware. On the left side, this space is used efficiently to house a combined control and power unit — the **Motor Driver Module**, which integrates the **Cytron MD13S motor driver** and the **TPS61088 voltage booster** (raising 5 V to 12 V).

This module demonstrates how the expansion bays can be used for compact and flexible system integration:
- The booster is attached with strong double-sided tape.
- The driver is mounted with screws.
- A small internal wall separates both components for added safety and stability.

At the rear, a **hexagonal connector pin** links the entire module directly to the chassis structure between the **Main Frame** and **Frame Back**, ensuring mechanical stability and clean routing of power lines.

---

## 36. Cable Box — Cable Management Module

<p align="left">

</p>

The right-side expansion bay is used for cable organization.  
The LiDAR unit came with a **1-meter cable**, which was too long for the compact chassis layout.  
Instead of cutting or replacing it, the cable was **carefully coiled** and placed inside this cable box, then lightly secured with **zip ties** to prevent movement without applying excess pressure on the housing.

This solution preserves cable integrity, maintains a clean internal layout, and avoids stress on connectors during operation.

---

## 37. LiDAR Driver Module

<p align="left">

</p>

This module holds the USB driver board for the RPLiDAR sensor, which comes included with the LiDAR unit.  
It is mounted between the Raspberry Pi and the top frame, where the mounting peg is slightly larger — making it impossible to attach from below without modifications.

For simplicity and reliability, the driver board is secured using **high-strength double-sided adhesive tape**.

# PART 4. PERFORMANCE

## 4.1 OPEN CHALLENGE ROUND

**PROGRAM LOGIC OVERVIEW**  
This section describes the software architecture that powers the robot’s autonomous behavior.  
The program is designed as a modular, multi-threaded system that integrates real-time data from LiDAR, camera, and IMU sensors, processes it efficiently, and converts it into stable motion control signals for the drivetrain and steering system.  

At a high level, the robot operates as a closed-loop system — continuously perceiving, analyzing, and acting:

1. **Perception Layer** – The robot gathers data from all sensors in parallel:  
   o LiDAR provides 2D environmental scans used to detect obstacles and walls.  
   o The camera supplies visual input for field recognition and visual correction.  
   o The IMU measures orientation and motion stability.

2. **Processing Layer** – Each data stream is handled in an independent thread:  
   o `scanThread()` updates LiDAR data through the **LidarStore** buffer.  
   o `cameraThread()` manages camera input through the **CameraStore**.  
   o Helper functions (`process_raw_frame`, `process_hsv`, `grayWorldWB`) normalize and filter images for geometric analysis.  
   o LiDAR data is preprocessed (`updateLidarData`, `combineLines`) to identify field edges and corners.

3. **Decision Layer** – Once the perception data is prepared, the robot interprets its position relative to the field geometry:  
   o `angle_between_lines`, `pointLinePerpendicularDistance`, and `lineIntersection` compute geometric relations.  
   o `nextCorner()` determines the next turn or checkpoint on the course based on these relationships.  
   o The robot keeps track of how many corners it has passed to evaluate mission progress.

4. **Action Layer** – Motor and steering commands are generated and executed:  
   o `motor()` controls the propulsion motor via PWM through the Cytron driver.  
   o `servo()` adjusts the steering angle with precision to match target headings.  
   o `fill()` and visualization utilities help debug and monitor the system’s understanding of its environment.

5. **Support and Control Infrastructure** –  
   The control logic is synchronized through lightweight shared-memory mechanisms:  
   o **LidarStore** and **CameraStore** manage real-time double-buffered data flow.  
   o `setup_GPIO()` initializes and configures GPIO pin modes.  
   o Diagnostic functions (`printDeviceInfo`, `checkHealth`) ensure hardware integrity before mission start.  
   o Power, logic, and sensor cycles are coordinated for stable operation at high frame rates.

# PROGRAM FLOW SUMMARY

## Initialization Phase

* The system boots, runs `setup_GPIO()`, and initializes LiDAR, camera, and IMU interfaces.
* Health checks are performed via `checkHealth()` and `printDeviceInfo()`.

## Runtime Phase

* Threads start: `scanThread()` (LiDAR) and `cameraThread()` (camera) run continuously.
* Buffers (`lidarStore`, `cameraStore`) update asynchronously, ensuring minimal latency.
* The main control loop periodically retrieves latest data, processes it, and computes the next steering and motor actions.

## Navigation Phase

* Image and LiDAR data are combined to estimate robot position relative to walls and corners.
* Using geometric computations (`angle between lines`, `nextCorner`, etc.), the robot plans turns and adjusts trajectory in real time.
* Every completed corner updates mission progress and stability checks.

## Safety and Reset

* If sensor data becomes unstable or incomplete, the system pauses and clears relevant buffers using `eraseLidarData()`.
* When safe, scanning and control threads resume normal operation.

## System Characteristics

* **Parallel execution** ensures fast response under changing field conditions.
* **Shared-memory synchronization** allows efficient data exchange without delay.
* **Compact C++ logic** minimizes overhead while providing real-time performance.
* **Geometry-based intelligence** replaces map-based navigation — the robot learns from live sensor feedback.

---

# SOFTWARE MODULE REFERENCE TABLE

| Layer | Module / Function | Purpose / Description |
|---|---|---|
| **Core System** | `setup_GPIO()` | Initializes all GPIO pins and sets their modes according to predefined constants. |
| | `motor(float speed)` | Controls main DC motor speed (0–1 range) through PWM to Cytron driver. |
| | `servo(float angle)` | Sets servo position according to the desired steering angle. |
| **LiDAR Subsystem** | `lidarStore` | Stores LiDAR scan data in two alternating buffers for efficient access and reduced latency. |
| | `printDeviceInfo(ILidarDriver* drv)` | Displays LiDAR identification and hardware parameters for verification. |
| | `checkHealth(ILidarDriver* drv)` | Monitors LiDAR operational status before scan start. |
| | `scanThread(ILidarDriver* drv)` | Runs in parallel, continuously reading new LiDAR frames into `lidarStore`. |
| | `eraseLidarData()` | Clears LiDAR data buffers before a new scan cycle. |
| | `updateLidarData()` | Converts raw LiDAR data into Cartesian and polar coordinate forms. |
| **Camera Subsystem** | `cameraStore` | Manages two frame buffers for fast image capture and access. |
| | `cameraThread(cv::VideoCapture* cap)` | Continuously reads camera frames and stores them in `cameraStore`. |
| | `process_raw_frame()` | Crops and preprocesses raw camera images to remove upper background zones. |
| | `process_hsv()` | Detects key color regions and masks relevant areas in HSV color space. |
| | `grayWorldWB()` | Applies automatic white balance correction for lighting consistency. |
| **Geometry & Navigation** | `angle_between_lines()` | Calculates the angle formed by intersecting line segments. |

---

# DETAILED PROGRAM FUNCTIONS' DESCRIPTION:

## 1. LiDAR Data Handling — LidarStore Module

The LidarStore namespace manages how LiDAR scan data is stored and accessed during operation.

It contains two internal buffers — `bufA` and `bufB` — that alternate between data collection and reading.

One buffer is always active and receives new LiDAR data, while the other remains available for access by other processes.

The program can request the latest LiDAR scan and its corresponding index, allowing consistent synchronization between data acquisition and navigation.

A separate parallel process updates these buffers in the background without interrupting access.

This structure helps the robot continuously receive fresh LiDAR information from the sensor while ensuring data integrity, even when multiple program threads run at the same time.

## 2. Camera Frame Management — CameraStore Module

The CameraStore namespace manages how images from the onboard camera are processed and stored for use in navigation and perception tasks.

It maintains two image buffers — `bufA` and `bufB` — which alternate between active and inactive states to ensure continuous frame updates without delays.

When a new frame arrives, it is written into the inactive buffer. Once ready, the program publishes it by switching the active index.

At any time, other processes can request the latest frame and its corresponding index for analysis.

A separate parallel process handles ongoing frame acquisition from the camera.

This setup allows the robot to keep receiving real-time video input while simultaneously using the most recent image for processing, without interrupting data flow or causing performance drops.

## 3. Recursive Fill Function — Visualization Utility

The `fill()` function implements a simple recursive flood-fill algorithm, similar to the "paint bucket" tool used in graphic editors.

Its purpose in the robot's visualization system is to make it easier to render or highlight regions of interest — for example, to display sensor coverage, obstacle areas, or path boundaries in test visualizations.

---

The function takes a pointer to a pixel array (`uchar* ptr`) and fills a connected area with a given value (`val`).

It uses recursion to propagate the fill operation in four directions — left, right, up, and down — within a defined rectangular boundary (e.g., `0L`, `w`, `0`, `h`).

This lightweight tool was designed for fast, memory-efficient graphical debugging, allowing to visually confirm how sensor data maps onto the environment during experiments.

## 4. GPIO Setup Function — Initialization Routine

The `setup_GPIO()` function initializes all Raspberry Pi GPIO pins according to the predefined constants used in the robot's control system.

Its role is to configure each pin with the correct direction (input/output) and mode (PWM, digital, etc.), ensuring that connected components such as the servo actuators, motor driver, and power logic can operate safely and predictably.

This setup is executed at program start and forms the foundation for all subsequent hardware interactions, providing a stable and consistent configuration baseline for the robot's control signals.

## 5. Servo Control Function — Angle-Based Positioning

The `servo(float angle)` function sets the rotation angle of the servo motor relative to its central (neutral) position.

It converts the given `angle` value into a corresponding PWM signal that determines the servo's shaft orientation.

This allows the robot to precisely control steering direction or mechanical articulation based on calculated geometry, ensuring accurate motion alignment between the servo and the rest of the drivetrain.

# 6. Motor Function — Speed Control Routine

The `motor(float speed)` function defines the rotation speed of the DC motor using a normalized value between `0` and `1`.

This value is translated into a PWM duty cycle that controls the effective voltage applied to the motor driver.

By adjusting the `speed` parameter, the program can smoothly regulate motor output — from a complete stop (`0`) to full power (`1`) — providing precise control over the robot's linear motion and acceleration.

## 7. printDeviceInfo Function — LiDAR Verification Utility

The `printDeviceInfo(ILidarDriver* drv)` function retrieves and displays basic device information from the connected LiDAR unit.

It is used for verification during initialization to confirm that the sensor is properly recognized and communicating with the system.

This routine outputs key parameters such as the model, firmware version, and hardware ID — allowing quick diagnostic checks before the main scanning process begins.

## 8. checkHealth Function — LiDAR Status Validation

The `checkHealth(ILidarDriver* drv)` function verifies the operational health of the LiDAR sensor before it starts scanning.

It queries the device for internal status reports to ensure there are no critical or warning-level errors.

This check is essential because the LiDAR is a complex and sensitive component — if its health status is not "OK," the system will avoid activating it to prevent unreliable operation or hardware malfunction.

## 9. scanThread Function — Parallel LiDAR Data Acquisition

The `scanThread(ILidarDriver* drv)` function runs as a dedicated parallel process responsible for continuously receiving scan data from the LiDAR sensor.

It collects distance and angle readings and writes them into the active data buffer maintained by the program.

This separation of scanning into its own thread ensures uninterrupted data acquisition — allowing other system components, such as navigation or visualization, to access the latest LiDAR data without delay or blocking.

## 10. cameraThread Function — Parallel Camera Frame Capture
The `cameraThread(cv::VideoCapture* cap)` function runs in a parallel thread and continuously reads frames from the robot's onboard camera.

Each captured frame is stored into one of two alternating memory buffers maintained by the system, ensuring smooth data flow and minimal delay.

This architecture allows the camera to operate independently from other processes such as navigation or mapping — keeping visual data constantly updated and accessible for analysis, display, or perception algorithms running on the main controller.

## 11. Angle Between Lines — Geometry Utility
The `angle_between_lines(const cv::Vec4i l1, const cv::Vec4i l2)` function computes the angle between two lines defined by OpenCV vectors (e.g., `x1`, `y1`, `x2`, `y2`).

It derives the direction of each line from its endpoints and returns the angle between these directions, treating the lines as infinitely extended (independent of their lengths or positions).

We use it for checking alignment, detecting corners, and validating geometric constraints in navigation or vision pipelines.

## 12. Process Raw Frame — Camera Preprocessing Function

The `process_raw_frame(uchar* raw_frame_p, uchar*& frame_p)` function processes raw camera input before it's used by the robot's main logic.

Its key role is to trim the upper portion of each captured frame — this removes unnecessary visual elements (like ceiling or distant background) that could distract the robot's perception algorithms.

The function operates as a lightweight preprocessing step, simplifying the visual field and ensuring that subsequent analysis focuses solely on the relevant ground-level area where navigation and obstacle detection occur.

## 13. Process HSV — Color Mask Extraction Function

The `process_hsv(uchar*& hsv_p, uchar*& red_p)` function processes the camera frame converted into the HSV color space and identifies specific color masks within it.

It isolates the areas of interest by filtering hues, saturation, and brightness levels corresponding to the target colors.

This allows the robot to recognize and track specific visual markers or colored objects on the field efficiently. The function prepares the image data for further analysis, ensuring consistent detection even under changing lighting conditions.

## 14. Point-to-Line Perpendicular Distance — Geometric Measurement Function

The `double pointLinePerpendicularDistance(const cv::Point2ds p, const cv::Vec4i& line)` function calculates the perpendicular distance from a given point to a specified line segment.

It is used to measure how far an object or detected feature lies from a reference line — a fundamental geometric operation for alignment, correction, or path-tracking tasks.

This function is essential for robot determining positional accuracy in navigation or for validating how closely detected contours match expected trajectories.

## 15. Middle Point — Line Center Calculation Helper
The `cv::Point2d middlePoint(const cv::Vec4i line)` function computes the midpoint of a given line segment.

It is a compact helper routine used to simplify geometric operations by quickly finding the center position between two endpoints.

We apply this function for visualization, alignment, and structural analysis of detected lines, helping reduce repetitive code and improve performance efficiency.

## 16. Line Intersection — Geometric Crosspoint Finder
The `cv::Point2d lineIntersection(const cv::Vec4i a, const cv::Vec4i b)` function determines the exact coordinates of the intersection point between two given lines, assuming they can be infinitely extended in both directions.

This function is used in the robot's geometry processing to analyze map structures, detect corners, and align navigation paths. It serves as a core mathematical utility that supports precise geometric reasoning based on LiDAR and camera line data.

## 17. Gray World White Balance — Brightness and Color Correction Function

The `void grayWorldWB(const cv::Mat& bgr, cv::Mat& bgrOut)` function performs automatic white balance correction based on the *gray world* assumption.

It adjusts the brightness and color balance of the image so that the program receives a more consistent visual feed — compensating for lighting variations such as direct sunlight, shadows, or low-light conditions.

This correction ensures that the robot's camera perceives colors and brightness more uniformly across environments, improving the accuracy of further image analysis and object detection.

## 18. Ray to Line Intersection Length — Directional Distance Calculation

The `long long RayToLineIntersectLength(cv::Vec4i a, const cv::Point2d b, double angle)` function calculates the distance between a given point and the intersection with a specified ray, along a ray projection from that point at a defined angle.

If the ray and line do not intersect, the function reports that no intersection exists.

We use it for geometric navigation logic — allowing the robot to determine how far it can "see" or move in a certain direction before encountering a boundary or detected line.

## 19. eraseLidarData — LiDAR Data Reset Routine

The `void eraseLidarData(all lidar arrays)` function clears all variables and buffers associated with LiDAR data.

Its purpose is to reset the LiDAR-related arrays after each processing cycle, ensuring that no residual data interferes with the next scan and that the system always works with a clean dataset for accurate readings.

## 20. updateLidarData — LiDAR Coordinate Formatting Function

The `void updateLidarData(auto& nodes, int nodes_count, auto& scanXY, auto& scanDa)` function converts incoming LiDAR measurements into three synchronized formats for further processing and visualization:

1. **Image Representation:** data is structured as a 2D visual map, where the LiDAR position is the center of the frame.
2. **Cartesian Coordinates:** points are translated into an X–Y coordinate system, where the origin is the upper-left corner of the image.
3. **Polar Coordinates:** each point is represented by its angle and distance from the LiDAR, treating the LiDAR as the origin.

This multi-format conversion allows the system to efficiently visualize, interpret, and process spatial data from the LiDAR for navigation and obstacle analysis.

## 21. combineLines — Line Grouping Function

The `void combineLines(auto& lines)` function processes an array of detected lines and merges those that are either very close to each other or nearly identical.

Its main goal is to simplify the dataset by combining redundant or overlapping lines into single, distinct segments.

This reduces computational load and ensures that only meaningful, distinct structural features are kept for further geometric analysis or path detection.

## 22. nextCorner — Next Turn Detection Function

The `cv::Point2d nextCorner(auto lines, int mainLineIdx)` function determines the coordinates of the next corner that the robot should reach while following a square path on the field.

Using the current main line (the robot's active trajectory) and the detected set of lines from the environment, it identifies the logical next corner in the robot's rotation cycle.

This is essential for navigation logic — since the robot must complete three laps around the field, it needs to continuously recognize when it reaches each corner to evaluate progress and adjust steering for the next segment of motion.

## 1. System Strategy — Autonomous Field Navigation

At program startup, the robot initializes all GPIO signals, essential constants, and runtime variables.

Once the activation button is pressed, the control system launches parallel threads for the LiDAR and camera subsystems, allowing real-time perception before motion begins.

Before enabling the motor, the LiDAR performs a pre-scan of the environment, measuring distances in four key diagonal directions — 45°, 135°, 225°, and 315°.

By comparing these measurements, the robot determines its initial orientation on the field without any prior movement.

This self-calibration method represents a major improvement over previous versions, where orientation drift at startup often caused early navigation errors.

After orientation is established, the robot enters its main operational loop, which continuously executes two parallel subsystems:

* **LiDAR-based Spatial Awareness** – The LiDAR system approximates the robot's current position relative to the map, allowing it to identify when it approaches a corner. The field is conceptually divided into eight angular sectors for simplified navigation and state tracking.
* **Camera-based Motion Control** – The camera subsystem maintains wall-following behavior using a PD algorithm. The image-processing pipeline detects the nearest boundary and adjusts the steering angle dynamically.

Together, these modules enable a hybrid control logic:

*"The camera shows the robot how to drive; the LiDAR tells it when to stop."*

When the final corner is passed, the robot continues forward for a fixed, pre-calibrated time interval — a constant determined experimentally to ensure it reaches the finish zone.

Upon arrival, the system stops the motor, safely terminates all background threads, and logs telemetry data such as camera frames, active masks, and other useful sensor information.
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

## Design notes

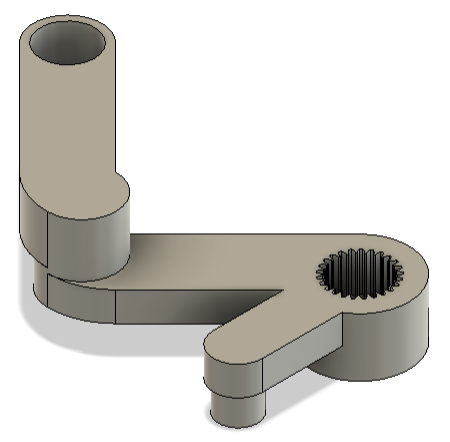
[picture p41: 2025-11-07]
Images/servo arm.png

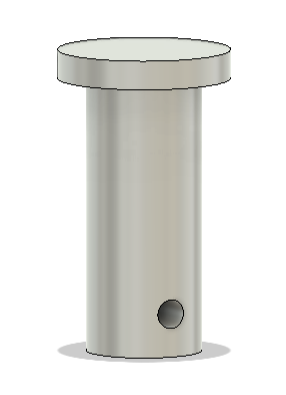
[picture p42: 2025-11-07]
Images/motor gear pin 2.png

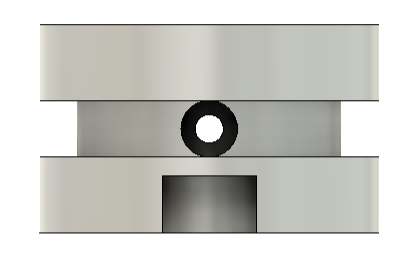
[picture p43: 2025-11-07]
Images/wheel 2.png

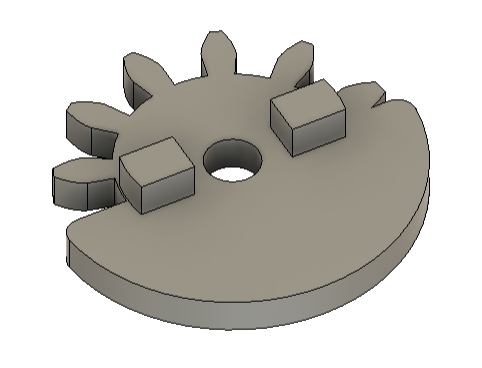
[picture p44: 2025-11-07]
Images/hinge cap (gear).png

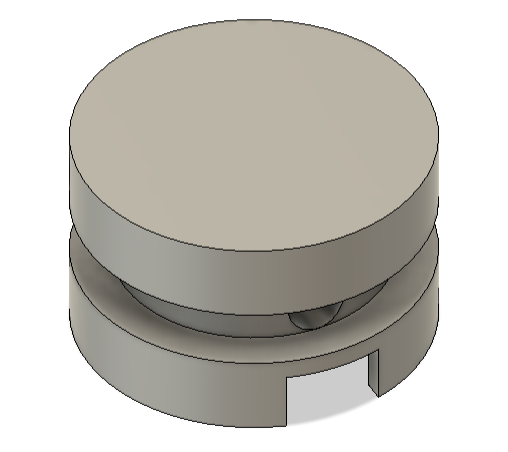
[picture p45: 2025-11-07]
Images/wheel 1.png

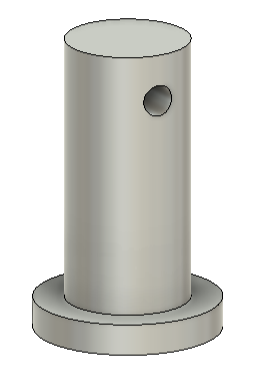
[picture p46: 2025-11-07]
Images/motor gear pin.png

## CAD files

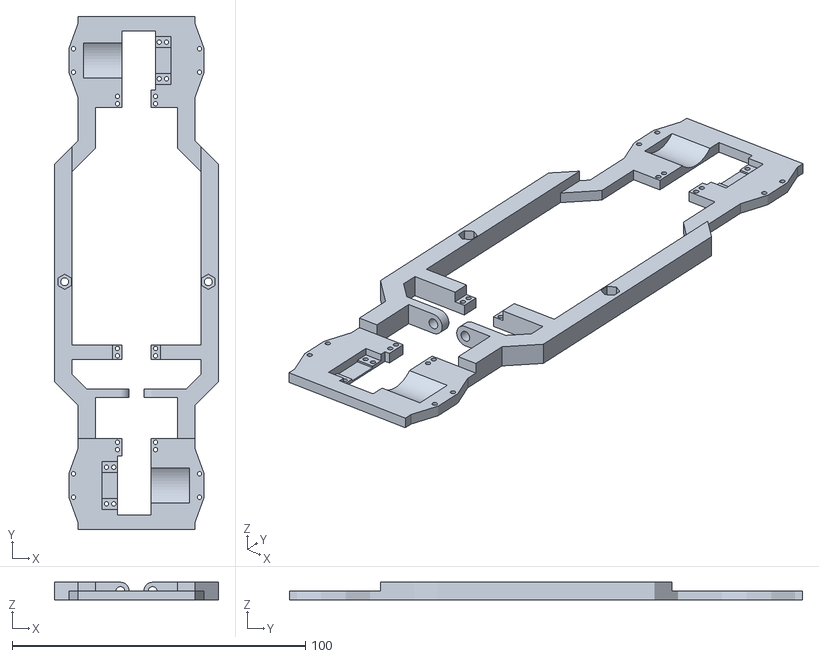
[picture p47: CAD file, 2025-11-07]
3D models/main frame.stl
56.0 x 175.0 x 6.00

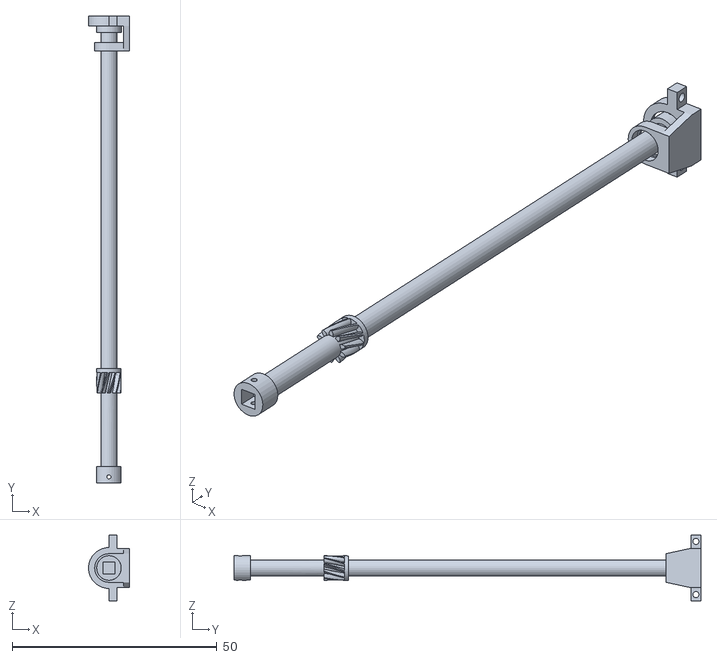
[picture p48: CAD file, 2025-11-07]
3D models/main axle.stl
9.98 x 114.0 x 16.0

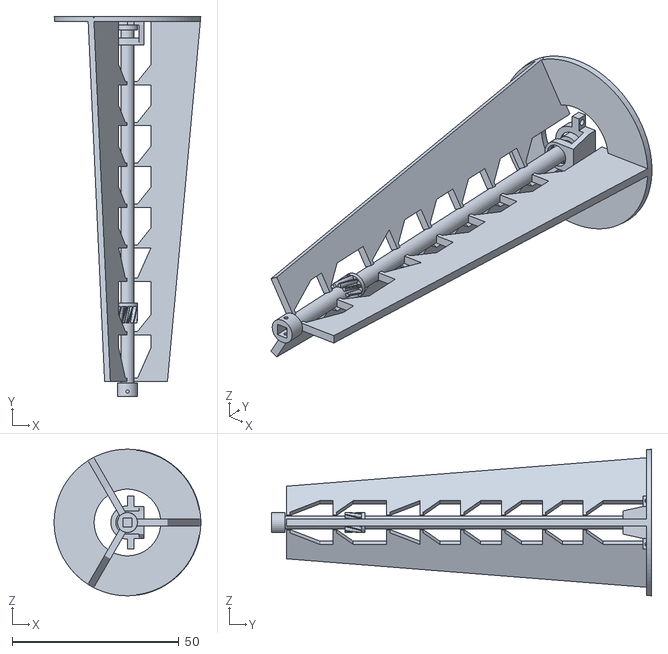
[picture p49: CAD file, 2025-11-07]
3D models/main axle with supports.stl
44.0 x 114.0 x 44.0

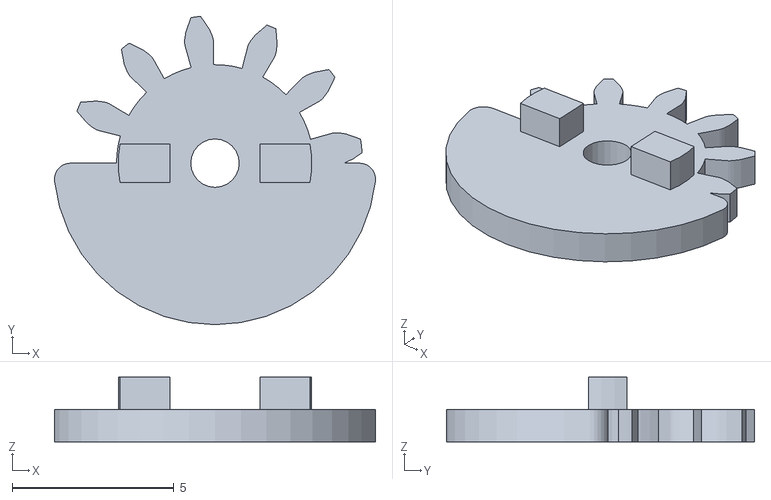
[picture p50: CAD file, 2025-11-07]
3D models/hinge cap (gear).stl
9.94 x 9.54 x 2.00

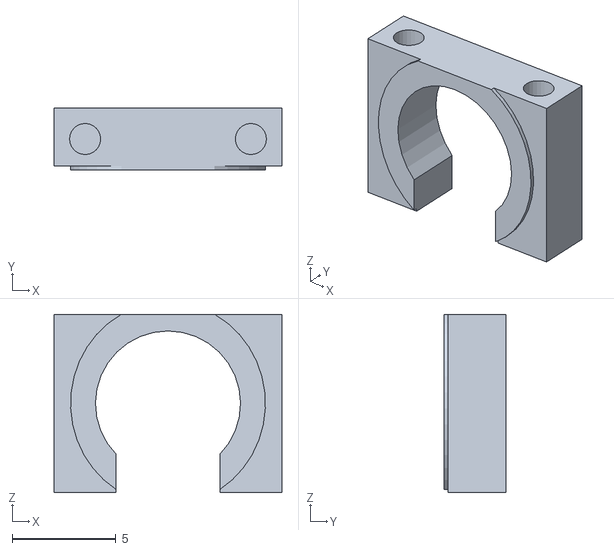
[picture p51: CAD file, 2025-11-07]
3D models/hinge support (open).stl
11.0 x 3.00 x 8.60

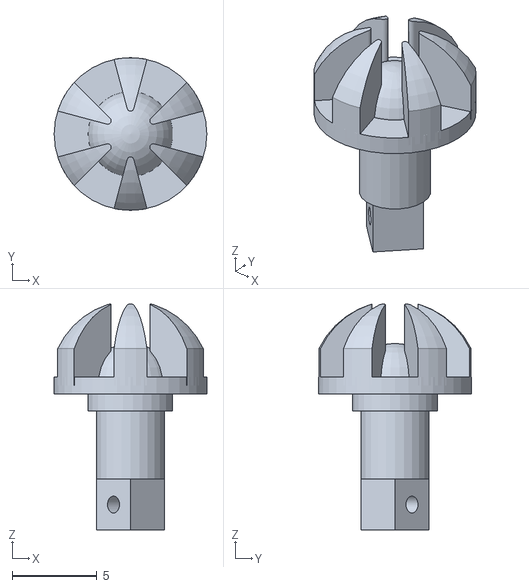
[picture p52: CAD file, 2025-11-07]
3D models/sung gear v8 short.stl
9.00 x 9.00 x 13.3

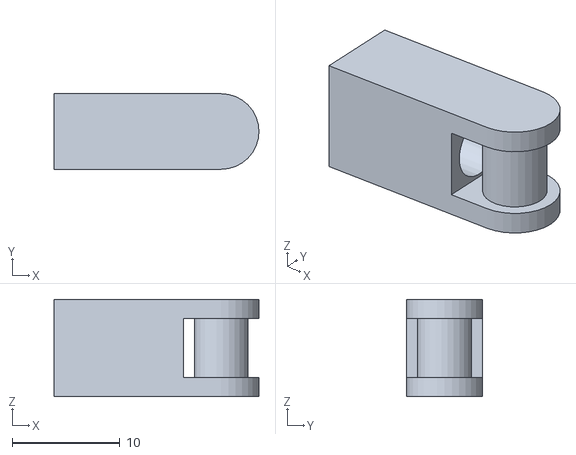
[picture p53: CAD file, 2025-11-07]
3D models/turn axle connector.stl
19.0 x 7.00 x 9.00

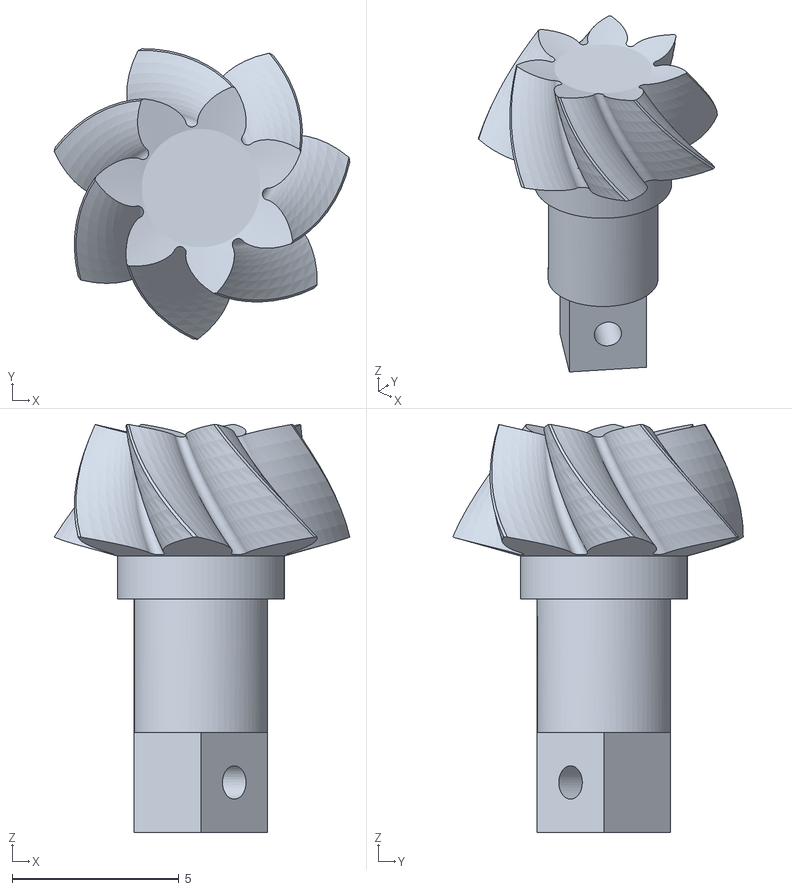
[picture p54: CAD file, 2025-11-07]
3D models/hypoid pinion.stl
8.87 x 8.71 x 12.2

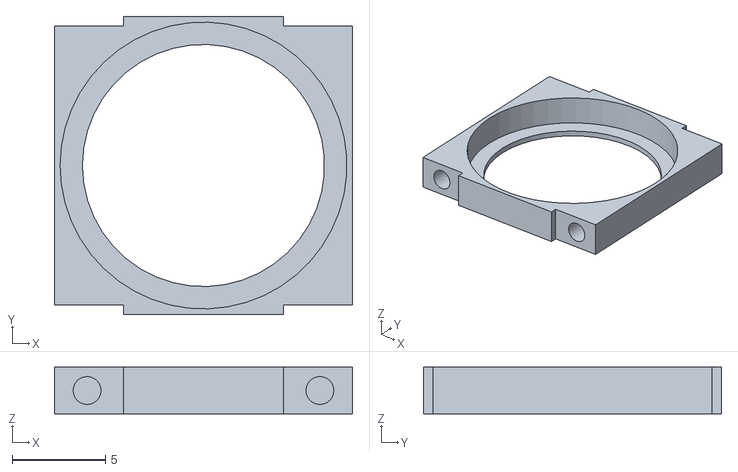
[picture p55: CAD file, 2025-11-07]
3D models/big ball bearing frame.stl
16.0 x 16.0 x 2.50

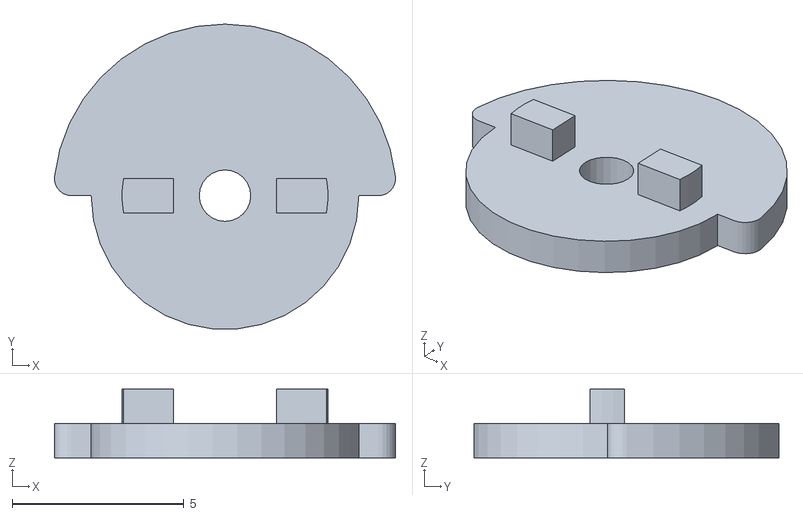
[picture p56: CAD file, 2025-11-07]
3D models/hinge cap.stl
9.94 x 8.88 x 2.00

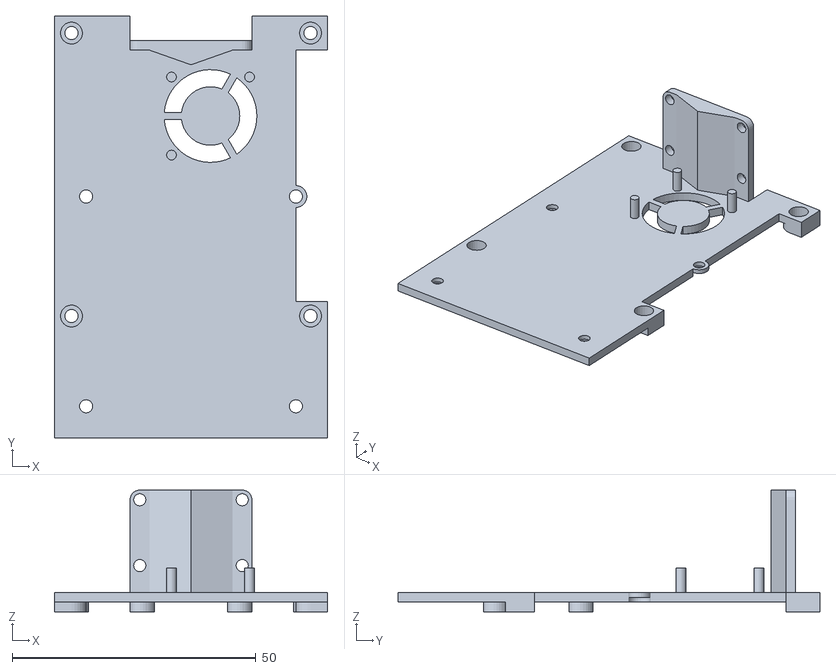
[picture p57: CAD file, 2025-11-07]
3D models/frame top.stl
56.0 x 86.5 x 25.0

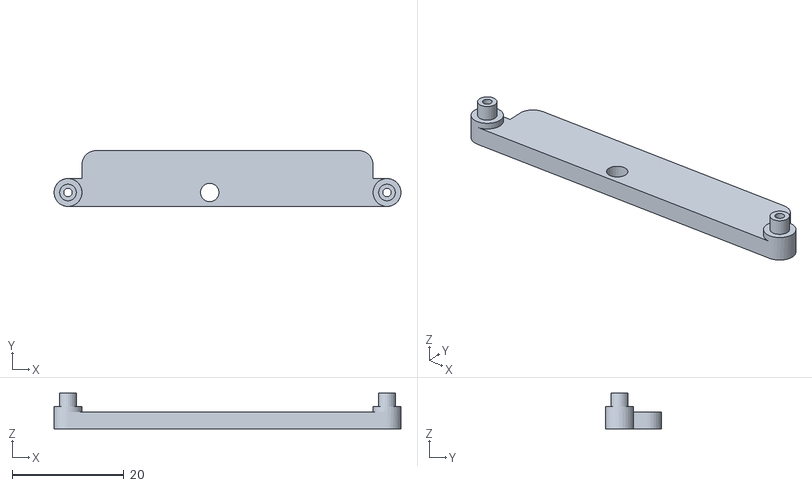
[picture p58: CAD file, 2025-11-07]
3D models/turn liftarm back.stl
62.0 x 10.0 x 6.40

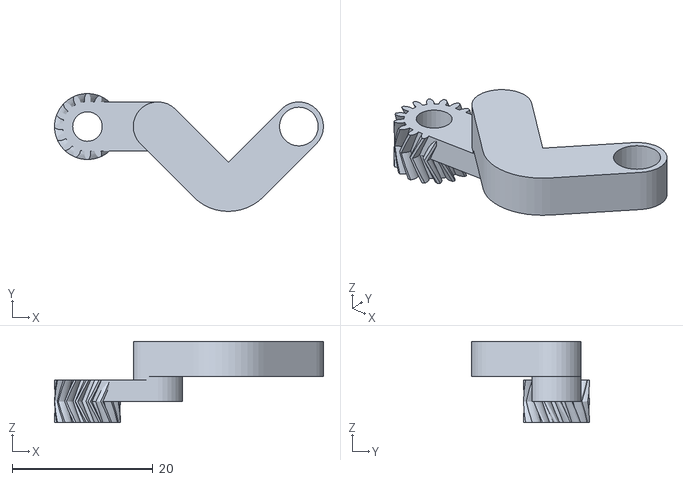
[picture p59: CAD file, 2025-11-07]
3D models/turn geared liftarm.stl
38.2 x 16.7 x 11.5

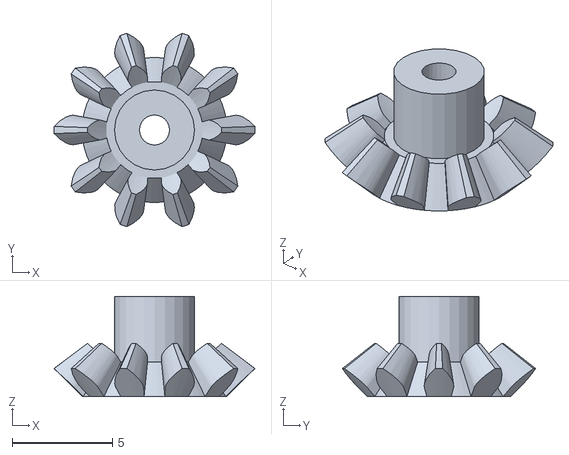
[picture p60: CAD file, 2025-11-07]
3D models/differential planetary pinion.stl
10.0 x 9.66 x 5.00

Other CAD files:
3D models/servo arm.stl
3D models/wheel v3.stl
3D models/lidar driver module.stl
3D models/bumper.stl
3D models/ball bearing frame with tube.stl
3D models/ball bearing frame.stl
3D models/cable box.stl
3D models/diamond-diamond axle connector.stl
3D models/differential pin.stl
3D models/differential sun gear long.stl
3D models/differential sun gear short.stl
3D models/differential.stl
3D models/frame back.stl
3D models/frame forward.stl
3D models/hinge arm L.stl
3D models/hinge arm R.stl
3D models/hinge connector.stl
3D models/hinge frame cover.stl
3D models/hinge frame robot side.stl
3D models/hinge frame wheel side.stl
3D models/hinge support.stl
3D models/motor driver module.stl
3D models/motor gear pin.stl
3D models/motor gear.stl
3D models/motor mount.stl
3D models/servo pin.stl
3D models/sun gear v8 long.stl
3D models/turn gear pin.stl
3D models/turn geared liftarm small.stl
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

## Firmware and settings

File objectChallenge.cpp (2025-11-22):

#include <iostream>
#include <pigpio.h>
#include <opencv2/opencv.hpp>
#include <csignal>
#include <cstdlib>
#include <cstdint>
#include <cstring>
#include <chrono>
#include <thread>
#include <atomic>

#include <fcntl.h>
#include <sys/socket.h>
#include <netinet/in.h>
#include <arpa/inet.h>
#include <sys/types.h>
#include <sys/wait.h>
#include <unistd.h>
#include <mutex>

#include "sl_lidar.h"
#include "sl_lidar_driver.h"
#pragma GCC optimize("Ofast")
//#pragma GCC target("avx,avx2,tune=native")

#define SERVO_PWM 12
#define MOTOR_PWM 13
#define MOTOR_DIR 17

#define BUTTON_PIN 24

using namespace sl;

namespace LidarStore {
    static sl_lidar_response_measurement_node_hq_t bufA[8192];
    static sl_lidar_response_measurement_node_hq_t bufB[8192];
    static std::atomic<size_t> countA{0}, countB{0};
    static std::atomic<int> active_idx{0}; // 0 = A active, 1 = B active
    static std::atomic<uint64_t> scan_idx{0};

    inline const sl_lidar_response_measurement_node_hq_t* get_latest(size_t& out_count, uint64_t& id) {
	id = scan_idx.load(std::memory_order_acquire);

        int idx = active_idx.load(std::memory_order_acquire);
        out_count = (idx==0) ? countA.load(std::memory_order_relaxed)
                             : countB.load(std::memory_order_relaxed);
        return (idx==0) ? bufA : bufB;
    }
}

namespace CameraStore {
    static cv::Mat bufA(480, 640, CV_8UC3);
    static cv::Mat bufB(480, 640, CV_8UC3);
    static std::atomic<int> active_idx{0}; // 0 = A active, 1 = B active
    static std::atomic<uint64_t> frame_idx{0};

    inline cv::Mat& get_inactive_buffer() {
        int idx = active_idx.load(std::memory_order_relaxed);
        return (idx == 0) ? bufB : bufA;
    }

    inline void publish() {
        int idx = active_idx.load(std::memory_order_relaxed);
        active_idx.store(1 - idx, std::memory_order_release);
        frame_idx.fetch_add(1, std::memory_order_relaxed);
    }

    inline const cv::Mat* get_latest(uint64_t& id) {
        int idx = active_idx.load(std::memory_order_acquire);
        id = frame_idx.load(std::memory_order_relaxed);
        return (idx == 0) ? &bufA : &bufB;
    }
}

static const auto T0 = std::chrono::steady_clock::now();
static inline uint64_t now_ns() {
    return std::chrono::duration_cast<std::chrono::nanoseconds>(
        std::chrono::steady_clock::now() - T0).count();
}

std::atomic<bool> running{true};
void onSigint(int) { running = false; }

size_t nodes_count = 0;
uint64_t scan_id = 0, scan_id_old = 0;
uint64_t frame_id = 0, frame_id_old = 0;


#pragma pack(push,1)
struct ImuHeader { uint8_t type, ver; uint16_t rsv; uint64_t t_ns; uint32_t seq; };
struct ImuPacket {
    ImuHeader h;
    float ax, ay, az;                  // linear accel (body)
    float qi, qj, qk, qr;              // quaternion (x,y,z,w)
    float gz;                          // gyro Z (rad/s) in body frame
};
#pragma pack(pop)

struct IMUSample {
    uint64_t t_ns;
    uint32_t seq;
    float ax, ay, az;
    float qi, qj, qk, qr;
    float gz; // rad/s
};

class IMUBuffer {
public:
    void reserve(size_t n) { std::lock_guard<std::mutex> lk(m_); buf_.reserve(n); }
    void push(const IMUSample& s) {
        std::lock_guard<std::mutex> lk(m_);
        buf_.emplace_back(s);
    }
    std::vector<IMUSample> take_and_clear() {
        std::lock_guard<std::mutex> lk(m_);
        std::vector<IMUSample> out;
        out.swap(buf_);                  // O(1) move, clears internal buffer
        if (buf_.capacity() < reserve_)  // keep a baseline reserve to avoid churn
            buf_.reserve(reserve_);
        return out;
    }
private:
    std::mutex m_;
    std::vector<IMUSample> buf_;
    size_t reserve_{1024};
};

namespace IMUStore {
    IMUBuffer log;
}

static pid_t spawn_python_bridge(const char* py, const char* script) {
    pid_t pid = fork();
    if (pid == 0) { execl(py, py, "-u", script, (char*)nullptr); perror("execl"); _exit(127); }
    if (pid < 0) perror("fork");
    return pid;
}

static void stop_python_bridge(pid_t pid, int grace_ms=300) {
    if (pid <= 0) return;
    kill(pid, SIGTERM);
    for (int i=0; i<grace_ms/10; ++i) {
        int st=0; pid_t r=waitpid(pid, &st, WNOHANG);
        if (r == pid) return;
        std::this_thread::sleep_for(std::chrono::milliseconds(10));
    }
    kill(pid, SIGKILL); waitpid(pid, nullptr, WNOHANG);
}

bool announced = false;

void imuThread() {
    #pragma pack(push,1)
    struct ImuHeader { uint8_t type, ver; uint16_t rsv; uint64_t t_ns; uint32_t seq; };
    struct ImuPacket { ImuHeader h; float ax, ay, az, qi, qj, qk, qr, gz; };
    #pragma pack(pop)

    constexpr int IMU_PORT = 5556;

    int fd = socket(AF_INET, SOCK_DGRAM, 0);
    if (fd < 0) { perror("imu socket"); return; }

    int yes = 1;
    setsockopt(fd, SOL_SOCKET, SO_REUSEADDR, &yes, sizeof(yes));
    int rcvbuf = 1<<20;
    setsockopt(fd, SOL_SOCKET, SO_RCVBUF, &rcvbuf, sizeof(rcvbuf));

    sockaddr_in a{};
    a.sin_family = AF_INET;
    a.sin_port   = htons(IMU_PORT);
    a.sin_addr.s_addr = htonl(INADDR_LOOPBACK);
    if (bind(fd, (sockaddr*)&a, sizeof(a)) < 0) {
        perror("imu bind");
        close(fd);
        return;
    }

    fcntl(fd, F_SETFL, O_NONBLOCK);
    IMUStore::log.reserve(4096);

    while (running.load(std::memory_order_relaxed)) {
        for (;;) {
            ImuPacket p{};
            ssize_t n = recv(fd, &p, sizeof(p), 0);
            if (n < 0) {
                break;
            }
            if (n == (ssize_t)sizeof(p) && p.h.type == 3 && p.h.ver == 2) {
                IMUSample s{
                    now_ns(),
                    p.h.seq,
                    p.ax, p.ay, p.az,
                    p.qi, p.qj, p.qk, p.qr,
                    p.gz
                };
                IMUStore::log.push(s);
                if (!announced) { std::cerr << "[imu] streaming (ver=2)\n"; announced = true; }
            }
        }
        std::this_thread::sleep_for(std::chrono::milliseconds(1));
    }

    close(fd);
}

bool direction = true; // true - clockwise

sl_lidar_response_measurement_node_hq_t nodes[8192];

cv::Mat m_map(620, 620, CV_8UC1);
uchar* map = m_map.data;

cv::Mat frame(240, 640, CV_8UC3);
cv::Mat image(240, 640, CV_8UC3);
cv::Mat hsv(240, 640, CV_8UC3);

cv::Mat red_mask(240, 640, CV_8UC1);
cv::Mat green_mask(240, 640, CV_8UC1);
cv::Mat pink_mask(240, 640, CV_8UC1);
cv::Mat wall_mask(240, 640, CV_8UC1);
uchar* red_mask_p = red_mask.data;
uchar* green_mask_p = green_mask.data;
uchar* pink_mask_p = pink_mask.data;
uchar* wall_mask_p = wall_mask.data;

cv::Mat m_draw(620, 620, CV_8UC1);
uchar* draw = m_draw.data;

int missMatchCounter = 0, ChangeZoneThreshould = 2, zone = 0;
bool zoneIsCorner = 0;

bool endgame = false;
double endTimer;

std::vector<std::array<int, 3> > scanXY;
std::vector<std::array<float, 3> > scanMA;

std::vector<cv::Vec4i> lines_raw;
std::vector<std::pair<float, cv::Vec4i> > lines;

int buttonSum = 0;

bool is_button_down() {
    if (gpioRead(BUTTON_PIN) == 0) {
        return true;
    } else {
        return false;
    }
}

void fill(uchar* ptr, int val, int x, int y, int x0, int y0, int w, int h) {
    if (ptr[x + w * y] == val) return;
    ptr[x + w * y] = val;
    if (x0 < x) fill(ptr, val, x-1, y, x0, y0, w, h);
    if (y0 < y) fill(ptr, val, x, y-1, x0, y0, w, h);
    if (x < x0 + w - 1) fill(ptr, val, x+1, y, x0, y0, w, h);
    if (y < y0 + h - 1) fill(ptr, val, x, y+1, x0, y0, w, h);
    return;
}

void setup_GPIO() {
    if (gpioInitialise() < 0) {
        std::cerr << "pigpio setup failed!\n";
        exit(1);
    }
    gpioSetMode(SERVO_PWM, PI_OUTPUT);
    gpioSetMode(MOTOR_PWM, PI_OUTPUT);
    gpioSetMode(MOTOR_DIR, PI_OUTPUT);

    gpioSetMode(BUTTON_PIN, PI_INPUT);
    gpioSetPullUpDown(BUTTON_PIN, PI_PUD_UP);
}

void servo(float angle) {
    int pulseWidth = (angle * 2000) + 500;
    gpioServo(SERVO_PWM, pulseWidth);
}

void motor(float speed) {
    speed *= 255;

    if (speed > 0) {
        gpioWrite(MOTOR_DIR, PI_HIGH);
    } else if (speed < 0) {
        speed = -speed;
        gpioWrite(MOTOR_DIR, PI_LOW);
    }

    if (speed > 255) speed = 255;

    gpioPWM(MOTOR_PWM, speed);
}

void printDeviceInfo(ILidarDriver* drv){
    sl_lidar_response_device_info_t info;
    if (SL_IS_OK(drv->getDeviceInfo(info))) {
        std::cerr << "Model " << (int)info.model
                  << " | FW " << ((info.firmware_version>>8)&0xFF) << "."
                  << (info.firmware_version & 0xFF)
                  << " | HW " << (int)info.hardware_version
                  << " | SN ";
        for (int i=0;i<16;++i) std::cerr << std::hex << (int)info.serialnum[i];
        std::cerr << std::dec << "\n";
    } else {
        std::cerr << "getDeviceInfo failed\n";
    }
}

bool checkHealth(ILidarDriver* drv){
    sl_lidar_response_device_health_t h;
    sl_result r = drv->getHealth(h);
    if (!SL_IS_OK(r)) {
        std::cerr << "getHealth failed, code=0x" << std::hex << r << std::dec << "\n";
        return false;
    }
    std::cerr << "Health status: " << (int)h.status << "\n";
    if (h.status == SL_LIDAR_STATUS_ERROR) {
        std::cerr << "Internal error reported. Power-cycle or reset.\n";
        return false;
    }
    return true;
}

void scanThread(ILidarDriver* drv){
    sl_lidar_response_measurement_node_hq_t local[8192];

    while (running.load(std::memory_order_relaxed)) {
        size_t count = sizeof(local)/sizeof(local[0]);
        sl_result res = drv->grabScanDataHq(local, count);
        if (!SL_IS_OK(res)) {
            std::this_thread::sleep_for(std::chrono::milliseconds(1));
            continue;
        }

        drv->ascendScanData(local, count);

	LidarStore::scan_idx.fetch_add(1, std::memory_order_relaxed);

        int cur = LidarStore::active_idx.load(std::memory_order_relaxed);
        if (cur == 0) {
            std::memcpy(LidarStore::bufB, local, count * sizeof(local[0]));
            LidarStore::countB.store(count, std::memory_order_relaxed);
            LidarStore::active_idx.store(1, std::memory_order_release);
        } else {
            std::memcpy(LidarStore::bufA, local, count * sizeof(local[0]));
            LidarStore::countA.store(count, std::memory_order_relaxed);
            LidarStore::active_idx.store(0, std::memory_order_release);
        }
    }
}

void cameraThread(cv::VideoCapture* cap) {
    while (running.load(std::memory_order_relaxed)) {
        cv::Mat& dst = CameraStore::get_inactive_buffer();
        if (cap->read(dst)) {
            CameraStore::publish();
        }
    }
}

double angle_between_lines(const cv::Vec4i& l1, const cv::Vec4i& l2) {
    cv::Point2d d1(l1[2] - l1[0], l1[3] - l1[1]);
    cv::Point2d d2(l2[2] - l2[0], l2[3] - l2[1]);

    double dot = d1.x * d2.x + d1.y * d2.y;
    double norm1 = std::hypot(d1.x, d1.y);
    double norm2 = std::hypot(d2.x, d2.y);

    if (norm1 == 0 || norm2 == 0) return 0.0;

    double cosTheta = dot / (norm1 * norm2);
    cosTheta = std::max(-1.0, std::min(1.0, cosTheta));

    double angle = std::acos(cosTheta) * 180.0 / CV_PI;

    return angle;
}

int center_distance(const cv::Vec4i& l1, const cv::Vec4i& l2) {
    cv::Point2d c1((l1[0] + l1[2]) / 2, (l1[1] + l1[3]) / 2);
    cv::Point2d c2((l2[0] + l2[2]) / 2, (l2[1] + l2[3]) / 2);
    return sqrt((c1.x - c2.x) * (c1.x - c2.x) + (c1.y - c2.y) * (c1.y - c2.y));
}

void process_hsv(uchar*& hsv_p, uchar*& red_p, uchar*& green_p, uchar*& pink_p, uchar*& wall_p) {
    int hue, sat, val;
    for (int p = 0; p < 240 * 640; p++) {
        red_p[p] = 0;
        green_p[p] = 0;
        pink_p[p] = 0;
        wall_p[p] = 0;

        hue = hsv_p[p * 3    ];
        sat = hsv_p[p * 3 + 1];
        val = hsv_p[p * 3 + 2];

        if (sat > 120 && val > 50 && val < 254) {
            if (hue < 15 || 175 < hue) {
                red_p[p] = 255;
            }
        }

        if (sat > 120 && val > 50 && val < 254) {
            if (45 < hue && hue < 90) {
                green_p[p] = 255;
            }
        }

        if (sat > 120 && val > 60 && val < 254) {
            if (135 < hue && hue <= 175) {
                pink_p[p] = 255;
            }
        }

        if (val < 60) {
            wall_p[p] = 255;
        }
    }
}

double pointLineDistance(const cv::Point2d& p, const cv::Vec4i& line) {
    double x1 = line[0], y1 = line[1];
    double x2 = line[2], y2 = line[3];

    double num = std::abs((x2 - x1)*(y1 - p.y) - (x1 - p.x)*(y2 - y1));
    double den = std::hypot(x2 - x1, y2 - y1);
    return den < 1e-9 ? 0.0 : num / den;
}

cv::Point2d middlePoint(const cv::Vec4i& line) {
    return cv::Point2d((line[2] + line[0]) >> 1, (line[3] + line[1]) >> 1);
}

int pointDistance(cv::Point2d a, cv::Point2d b) {
    return std::sqrt((a.x - b.x) * (a.x - b.x) + (a.y - b.y) * (a.y - b.y));
}

inline cv::Point2d lineIntersection(const cv::Vec4i& a, const cv::Vec4i& b) {
    cv::Point2d p1(a[0], a[1]), p2(a[2], a[3]);
    cv::Point2d q1(b[0], b[1]), q2(b[2], b[3]);

    double A1 = p2.y - p1.y;
    double B1 = p1.x - p2.x;
    double C1 = A1 * p1.x + B1 * p1.y;

    double A2 = q2.y - q1.y;
    double B2 = q1.x - q2.x;
    double C2 = A2 * q1.x + B2 * q1.y;

    double det = A1 * B2 - A2 * B1;

    // since lines always intersect, det != 0
    return cv::Point2d(
        (B2 * C1 - B1 * C2) / det,
        (A1 * C2 - A2 * C1) / det
    );
}

void process_raw_frame(uchar* raw_frame_p, uchar*& frame_p) {
    int p1 = 0, p2 = 640 * 240 * 3;
    for (int y = 240; y < 480; ++y) {
	for (int x = 0; x < 640; ++x) {
	    frame_p[p1] = raw_frame_p[p2];
	    frame_p[p1 + 1] = raw_frame_p[p2 + 1];
	    frame_p[p1 + 2] = raw_frame_p[p2 + 2];

	    p1 += 3;
	    p2 += 3;
	}
    }
}

void grayWorldWB(const cv::Mat& bgr, cv::Mat& bgrOut) {
    CV_Assert(bgr.type() == CV_8UC3);
    cv::Scalar m = cv::mean(bgr); // B,G,R
    double gray = (m[0] + m[1] + m[2]) / 3.0;
    cv::Mat gain = (cv::Mat_<double>(1,3) << gray/(m[0]+1e-6),
                                             gray/(m[1]+1e-6),
                                             gray/(m[2]+1e-6));
    bgr.convertTo(bgrOut, CV_32F);
    cv::multiply(bgrOut, gain, bgrOut);
    cv::Mat tmp;
    cv::normalize(bgrOut, tmp, 0, 255, cv::NORM_MINMAX);
    tmp.convertTo(bgrOut, CV_8U);
}

long long RayToLineIntersectLength(cv::Vec4i a, const cv::Point2d b, double angle) {
    a[0] -= b.x;
    a[1] -= b.y;
    a[2] -= b.x;
    a[3] -= b.y;

    double m1 = std::hypotf(float(a[0]), float(a[1]));
    double m2 = std::hypotf(float(a[2]), float(a[3]));

    double a1 = std::atan2(float(a[1]), float(a[0])) - angle;
    double a2 = std::atan2(float(a[3]), float(a[2])) - angle;

    a[0] = m1 * std::cos(a1);
    a[1] = m1 * std::sin(a1);
    a[2] = m2 * std::cos(a2);
    a[3] = m2 * std::sin(a2);


    cv::Point2d p1(a[0], a[1]), p2(a[2], a[3]);

    double A1 = p2.y - p1.y;
    double B1 = p1.x - p2.x;
    double C1 = A1 * p1.x + B1 * p1.y;

    if (B1 == 0) return -1;

    long long y = C1 / B1;

    if (y > 0) return -1;
    return -y;
}

void nextCorner(int& x, int &y, int idx) {
    x = 0;
    y = 0;
    for (int j = 0; j < lines.size(); j++) if (j != idx) {
	double angle = angle_between_lines(lines[idx].second, lines[j].second);
	if (angle > 90.0) angle = 180.0 - angle;
	if (angle > 80) {
	    cv::Point intersect = lineIntersection(lines[idx].second, lines[j].second);
	    if (intersect.x > x) {
		x = intersect.x;
		y = intersect.y;
	    }
	}
    }
    return;
}

void findDirection() {
    while (running.load(std::memory_order_relaxed)) {
	const auto* nodes = LidarStore::get_latest(nodes_count, scan_id);
	if (scan_id > 2) {
	    std::vector <long long> sum(361, 0);
	    for (int i = 0; i < nodes_count; i++) if (nodes[i].dist_mm_q2 != 0) {
		float angle = nodes[i].angle_z_q14 * 90.f / 16384.f * M_PI / 180;
		float dist = nodes[i].dist_mm_q2 / 40.f;
		int idx = angle * 180 / M_PI;
		sum[idx+1] += dist;
	    }
	    for (int i = 1; i <= 360; i++) sum[i] += sum[i-1];

	    long long sumAt90 = sum[90+15] - sum[90-16];
	    long long sumAt270 = sum[270+15] - sum[270-16];
	    if (sumAt90 >= sumAt270) {
		std::cout << "CLOCKWISE\n";
		direction = true;
	    } else {
		std::cout << "COUNTERCLOCKWISE\n";
		direction = false;
	    }
	    break;
	}
    }
}

void mergeAllLines() {
    for (auto it1 = lines.begin(); it1 != lines.end(); ++it1) {
	auto it2 = std::next(it1);
	while (it2 != lines.end()) {
	    double angle = angle_between_lines(it1->second, it2->second);
	    if (angle > 90.0) angle = 180.0 - angle;
	    if (angle < 30.0 && pointLineDistance(cv::Point((it2->second[2] + it2->second[0])/2, (it2->second[3] + it2->second[1]) / 2), it1->second) < 10) {
		cv::Point points[4];
		points[0] = {it1->second[0], it1->second[1]};
		points[1] = {it1->second[2], it1->second[3]};
		points[2] = {it2->second[0], it2->second[1]};
		points[3] = {it2->second[2], it2->second[3]};
		int best_length = it1->first;
		int best_x = 0, best_y = 1;
		for (int i = 0; i < 3; i++) {
		    for (int j = i + 1; j < 4; j++) {
			int current_l = std::hypot(points[i].x - points[j].x, points[i].y - points[j].y);
			if (current_l > best_length) best_x = i, best_y = j, best_length = current_l;
		    }
		}
		it1->second[0] = points[best_x].x;
		it1->second[1] = points[best_x].y;
		it1->second[2] = points[best_y].x;
		it1->second[3] = points[best_y].y;

		it2 = lines.erase(it2);
	    } else {
		++it2;
	    }
	}
	it1->first = std::hypot((it1->second[2] - it1->second[0]), (it1->second[3] - it1->second[1]));
    }
}

void rideAtAngle(double A, double time) {
    double beginTime = now_ns();
    double err = 0, errold = 0;

    auto imu_batch = IMUStore::log.take_and_clear();
    while (running.load(std::memory_order_relaxed)) {
	auto imu_batch = IMUStore::log.take_and_clear();

	if (!imu_batch.empty()) {
	    // y back, x right
	    static uint64_t prev_ns = 0;
	    double axl, ayl, ax, ay;
	    for (const auto& s : imu_batch) {
		double dt = (prev_ns == 0) ? 0.0 : (double)(s.t_ns - prev_ns) * 1e-9;
		if (dt <= 0.0) dt = 0.000001;
		dt = (dt > 0.02) ? 0.02 : dt;
		prev_ns = s.t_ns;

		float w = s.qr, x = s.qi, y = s.qj, z = s.qk;
		float n = std::sqrt(w*w + x*x + y*y + z*z);
		if (n > 0.0f) { w /= n; x /= n; y /= n; z /= n; }
		double a = std::atan2(float(2.0f * (w*z + x*y)), float(1.0f - 2.0f * (y*y + z*z)));
		a = a + 2 * M_PI;
		if (a > 2 * M_PI) a -= 2 * M_PI;

		double dir = 0.48;
		err = a - A;
		dir = 0.48 + err * 0.25 + (err - errold) * 5;
		dir = std::min(std::max(dir, 0.42), 0.54);
		servo(dir);
		errold = err;
	    }
	}

	if (now_ns() - beginTime >= time) break;

	if (is_button_down()) buttonSum++;
	else buttonSum--;
	if (buttonSum < 0) buttonSum = 0;
	if (buttonSum > 100) running = false;
    }
}
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
int main() {
    const char* port = "/dev/ttyUSB0";
    int baud = 1000000;

    std::signal(SIGINT, onSigint);

    setup_GPIO();

    motor(0);

    const std::string pipeline =
    "libcamerasrc ! "
    "video/x-raw,width=640,height=480,framerate=30/1 ! "
    "videoconvert ! video/x-raw,format=BGR ! "
    "queue max-size-buffers=1 leaky=downstream ! "
    "appsink drop=true max-buffers=1 sync=false";

    cv::VideoCapture cap(pipeline, cv::CAP_GSTREAMER);
    if (!cap.isOpened()) { std::cerr << "camera open failed\n"; return 2; }

    ILidarDriver* drv = *createLidarDriver();
    if (!drv) { std::cerr << "createLidarDriver failed\n"; return 3; }

    IChannel* ch = *createSerialPortChannel(port, baud);
    if (!ch) {
	std::cerr << "createSerialPortChannel failed for " << port << "\n";
	delete drv; return 4;
    }

    if (SL_IS_FAIL(drv->connect(ch))) {
	std::cerr << "connect failed: " << port << " @ " << baud << "\n";
	delete ch; delete drv; return 5;
    }

    printDeviceInfo(drv);
    if (!checkHealth(drv)) { drv->disconnect(); delete ch; delete drv; return 6; }

    drv->setMotorSpeed();

    if (SL_IS_FAIL(drv->startScan(false, true))) {
	std::cerr << "startScan failed\n"; drv->setMotorSpeed(0);
	drv->disconnect(); delete ch; delete drv; return 7;
    }

    const char* PY     = "/home/peter/bno-venv/bin/python";
    const char* SCRIPT = "/home/peter/wro/bno.py";
    pid_t imu_child = spawn_python_bridge(PY, SCRIPT);
    if (imu_child <= 0) std::cerr << "Failed to start IMU bridge\n";

    buttonSum = 0;
    while (buttonSum < 50) {
	if (is_button_down()) buttonSum++;
	else buttonSum--;
	if (buttonSum < 0) buttonSum = 0;
    }
    buttonSum = 0;

    std::thread imu_thread(imuThread);
    std::thread lidar_thread(scanThread, drv);
    std::thread camera_thread(cameraThread, &cap);

    servo(0.48);

    findDirection();

    while (!announced) {} // waiting for IMU to start

    unpark()

    motor(0.51);
    main_cycle();

    if (direction) rotate();

    goToParking(0.7);

    motor(-0.3);
    wait(100e6);

    park();

    motor(0);
    servo(0.48);

    cv::Point center_point(310, 310);
    cv::circle(m_map, center_point, 5, 200, 2);
    cv::imwrite("lidar.png", m_map);
    cv::imwrite("frame.png", frame);
    cv::imwrite("image.png", image);
    cv::imwrite("red mask.png", red_mask);
    cv::imwrite("green mask.png", green_mask);
    cv::imwrite("pink mask.png", pink_mask);
    cv::imwrite("wall mask.png", wall_mask);


    running = false;
    drv->stop();
    if (lidar_thread.joinable()) lidar_thread.join();
    if (camera_thread.joinable()) camera_thread.join();
    if (imu_thread.joinable()) imu_thread.join();
    drv->setMotorSpeed(0);
    drv->disconnect();
    stop_python_bridge(imu_child);
    delete ch;
    delete drv;

    return 0;
}

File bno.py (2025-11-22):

#!/usr/bin/env python3
import socket, struct, time, errno, signal, os

from adafruit_extended_bus import ExtendedI2C as I2C
try:    from adafruit_bno08x.i2c import BNO08X_I2C
except: from adafruit_bno08x import BNO08X_I2C

# Feature constants (support both older/newer layouts; final fallback numeric is best-effort)
try:
    from adafruit_bno08x import (
        BNO_REPORT_LINEAR_ACCELERATION,
        BNO_REPORT_ROTATION_VECTOR,
        BNO_REPORT_GYROSCOPE,
    )
except Exception:
    try:
        from adafruit_bno08x.features import (
            BNO_REPORT_LINEAR_ACCELERATION,
            BNO_REPORT_ROTATION_VECTOR,
            BNO_REPORT_GYROSCOPE,
        )
    except Exception:
        BNO_REPORT_LINEAR_ACCELERATION = 0x04
        BNO_REPORT_ROTATION_VECTOR     = 0x05
        BNO_REPORT_GYROSCOPE           = 0x08  # library should provide this; numeric is a fallback

# Config
BUS, ADDR = 1, 0x4A
HOST = os.getenv("BNO_UDP_HOST", "127.0.0.1")
PORT = int(os.getenv("BNO_UDP_PORT", "5556"))
DEST = (HOST, PORT)
MAXERRS = 5
SLEEP_S = 0.0

STOP = False
def _sig(_n, _f):
    global STOP; STOP = True
signal.signal(signal.SIGINT, _sig)
signal.signal(signal.SIGTERM, _sig)

# Header + Body (VER=2, adds gz)
TYPE_COMBINED, VER = 3, 2
HDR  = struct.Struct("<BBH Q I")     # type, ver, rsv, t_ns, seq  (16 bytes)
BODY = struct.Struct("<fff ffff f")  # ax,ay,az, qi,qj,qk,qr, gz  (32 bytes) => total 48
BUF  = bytearray(HDR.size + BODY.size)

def enable_features(bno):
    for feat in (BNO_REPORT_LINEAR_ACCELERATION, BNO_REPORT_ROTATION_VECTOR, BNO_REPORT_GYROSCOPE):
        try:
            bno.enable_feature(feat, report_interval_us=2500)
        except TypeError:
            bno.enable_feature(feat)

def open_sensor():
    i2c = I2C(BUS)
    bno = BNO08X_I2C(i2c, address=ADDR)
    try:
        if hasattr(bno, "soft_reset"):
            bno.soft_reset(); time.sleep(0.002)
    except Exception:
        pass
    enable_features(bno)
    # brief drain
    t_end = time.time() + 0.05
    while time.time() < t_end:
        try:
            _ = bno.linear_acceleration; _ = bno.quaternion
            _ = getattr(bno, "gyro", getattr(bno, "gyroscope", None))
        except Exception:
            pass
    return i2c, bno

def main():
    sock = socket.socket(socket.AF_INET, socket.SOCK_DGRAM)
    try: sock.setsockopt(socket.SOL_SOCKET, socket.SO_SNDBUF, 1<<20)
    except Exception: pass

    seq = 0
    t0_ns = time.monotonic_ns()

    while not STOP:
        try:
            i2c, bno = open_sensor()
            err = 0
            last_gz = 0.0
            while not STOP:
                try:
                    la = bno.linear_acceleration
                    q  = bno.quaternion
                    g  = getattr(bno, "gyro", getattr(bno, "gyroscope", None))
                    gz = (g[2] if g else last_gz)
                    if la and q:
                        seq += 1
                        t_ns = time.monotonic_ns() - t0_ns
                        HDR.pack_into(BUF, 0, TYPE_COMBINED, VER, 0, t_ns, seq)
                        BODY.pack_into(BUF, HDR.size, la[0], la[1], la[2], q[0], q[1], q[2], q[3], gz)
                        sock.sendto(BUF, DEST)
                        last_gz = gz
                        err = 0
                    if SLEEP_S: time.sleep(SLEEP_S)
                except (KeyError, IndexError, OSError):
                    err += 1
                    time.sleep(0.001)
                    if err >= MAXERRS:
                        try:
                            if hasattr(bno, "soft_reset"):
                                bno.soft_reset(); time.sleep(0.002)
                            enable_features(bno)
                        except Exception:
                            try: i2c.deinit()
                            except Exception: pass
                            break
                except Exception:
                    time.sleep(0.001)

            try:
                if hasattr(bno, "soft_reset"): bno.soft_reset()
            except Exception: pass
            try: i2c.deinit()
            except Exception: pass
            if not STOP: time.sleep(0.02)

        except Exception:
            time.sleep(0.1)

if __name__ == "__main__":
    main()
